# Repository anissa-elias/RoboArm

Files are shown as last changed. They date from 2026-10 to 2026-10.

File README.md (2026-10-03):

# RoboArm

An open, low-cost 6-axis robotic arm built entirely from commercial off-the-shelf (COTS) parts, designed for students to build, program and learn from.

RoboArm aims for the feature set of an educational desktop arm such as the Niryo Ned2 (onboard computer running ROS 2, joint encoders, collision detection, emergency stop) at a fraction of the cost, with every purchased part available on Amazon.

> Status: early design. The electronics schematic and bill of materials are complete and checked. The mechanical design, firmware and ROS 2 software are not started yet.

## Features (planned)

| Feature | How |
|---|---|
| 6 joints + gripper | NEMA 17 stepper motors, MG996R gripper servo |
| Onboard brain | Raspberry Pi 5 running ROS 2 Jazzy (Ubuntu 24.04) |
| Real-time motion | Arduino Mega 2560 generating step pulses |
| Quiet drivers | TMC2209 stepper drivers |
| Knows where it is at power-up | AS5600 absolute magnetic encoder on every joint output, no homing move |
| Collision and load sensing | TMC2209 StallGuard load readings over UART, per joint |
| Safety | Latching E-stop that drops a relay on the 24 V motor bus |
| Simple to source | Every purchased part on Amazon |

## How it works

```
Raspberry Pi 5 (ROS 2)  --USB-->  Arduino Mega 2560  --STEP/DIR/EN-->  6x TMC2209  -->  6x NEMA 17
                                       |  <--UART (load, temperature, open-wire)--  TMC2209
                                       |  <--analog angle--  6x AS5600 joint encoders
                                       +--PWM-->  gripper servo

24 V bench supply -> 10 A fuse -> E-stop relay -> 24 V bus -> drivers
                                                          -> 2 A fuse -> 6 V buck -> gripper servo
Pi 5 has its own USB-C supply and powers the Mega over USB.
```

Details: [docs/architecture.md](docs/architecture.md).

## Repository layout

| Folder | Contents |
|---|---|
| [hardware/electronics/](hardware/electronics/) | KiCad schematic (every pin shown), generator script, connection checker, PDF |
| [hardware/bom/](hardware/bom/) | Bill of materials with Amazon links |
| [hardware/mechanical/](hardware/mechanical/) | 3D-printed body, CAD, print settings (open) |
| [firmware/](firmware/) | Arduino Mega firmware (open) |
| [software/](software/) | ROS 2 packages, simulation, tools (open) |
| [docs/](docs/) | Architecture, design decisions, roadmap |

## Cost

Electronics and motors: about **$268** before tax and shipping (estimate, see [hardware/bom/](hardware/bom/)). This excludes the Raspberry Pi 5, its power supply, the Arduino Mega, a 24 V bench supply, printed parts and mechanical hardware. Target: a complete arm cheaper than comparable open-source arms.

## Roadmap

See [docs/roadmap.md](docs/roadmap.md).

## Related open-source arms

RoboArm learns from existing open designs, including [Thor](https://github.com/AngelLM/Thor), [PAROL6](https://github.com/Source-Robotics/PAROL6-Desktop-robot-arm), [Faze4](https://github.com/Source-Robotics/Faze4-Robotic-arm), [SmallRobotArm](https://github.com/SkyentificGit/SmallRobotArm) and the [AR4](https://www.anninrobotics.com). See [docs/comparison.md](docs/comparison.md).

## Safety

This is an experimental machine. Motors can move suddenly and pinch. Keep the E-stop within reach, set a current limit on the supply during first tests, and never plug or unplug a motor with power applied.

## License

To be decided.

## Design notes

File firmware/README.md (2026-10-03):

# Firmware (Arduino Mega 2560)

`roboarm_mega/` is the motion-controller firmware. Pin map: [docs/architecture.md](../docs/architecture.md#arduino-mega-pin-map).

| File | Contents |
|---|---|
| `roboarm_mega.ino` | Serial protocol to the Pi, safety checks, gripper |
| `motion.cpp/.h` | Step generation (Timer2 ISR, 20 kHz) and per-joint trapezoidal velocity planning, all joints arrive together |
| `sensors.cpp/.h` | AS5600 encoder reading and zero offsets (EEPROM), TMC2209 UART setup and polling (load, over-temperature, open wire) |
| `config.h` | Pins, gear ratios, limits, currents, speeds. **Gear ratios and limits are placeholders until the mechanical design exists.** |

## Build

```bash
arduino-cli core install arduino:avr
arduino-cli lib install TMCStepper Servo
arduino-cli compile -b arduino:avr:mega firmware/roboarm_mega
# with nothing connected (fake encoders and drivers):
arduino-cli compile -b arduino:avr:mega --build-property build.extra_flags=-DRA_SIM=1 firmware/roboarm_mega
```

Or use the dev image, which has the toolchain: see [software/README.md](../software/README.md).

## Protocol (USB serial, 115200 baud, one command per line)

| Command | Meaning |
|---|---|
| `P` | Ping (keeps the 1 s link watchdog alive) |
| `E 1` / `E 0` | Enable / disable all drivers |
| `M a1 ... a6` | Move all joints to angles (degrees) |
| `J n a` | Move joint n to angle a |
| `X` | Stop smoothly |
| `V dps` / `A dps2` | Max joint speed / acceleration |
| `G a`, `G O`, `G C` | Gripper angle, open, close |
| `S` | Status line |
| `T hz` | Stream status (0 = off, max 50) |
| `Z` | Current pose becomes encoder zero (saved) |
| `R` | Re-sync step counters to encoders |
| `L n thr` | StallGuard threshold for joint n (0 = off) |
| `C` | Clear faults |

Status line: `S <faults> <enabled> <moving> | 6 commanded angles | 6 encoder angles | 6 loads | 6 driver flags`.
Fault bits: 1 link lost, 2 collision, 4 following error (> 5 deg between commanded and encoder), 8 no motor power (E-stop or 24 V off), 16 driver fault (open wire).

## Known limits (from the design review)

- The ATmega2560 tops out around 10 kHz steps per joint; with large gear reductions this limits joint speed. A faster motion MCU (Teensy 4.1 or a 6-driver STM32 board) is under consideration.
- TMC2209 registers reset when motor power drops; the firmware re-sends settings when a driver answers again, and stays disabled until faults are cleared.
- StallGuard only works while moving, in StealthChop; collision detection relies mainly on the encoder following error.
- TODO: E-stop input to the MCU, DIAG pin interrupts, encoder range/linearity calibration.

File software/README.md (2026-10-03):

# Software (Raspberry Pi 5)

Target: Ubuntu 24.04 with ROS 2 Jazzy on the Raspberry Pi 5, run in Docker so the same environment works on a dev machine and on the Pi.

## Dev environment (Docker)

`docker/Dockerfile` builds `roboarm-dev:jazzy`: ROS 2 Jazzy, ros2_control, Arduino CLI with the AVR core and firmware libraries, and Python serial tools. The same Dockerfile builds for amd64 (dev machine or VM) and arm64 (Raspberry Pi 5).

```bash
docker compose -f software/docker/compose.yaml build
docker compose -f software/docker/compose.yaml run --rm dev        # shell with the repo at /roboarm
```

On the Pi with the Mega plugged in, uncomment the `devices:` block in `compose.yaml` to pass `/dev/ttyACM0` into the container.

## Working with nothing connected

| Tool | Purpose |
|---|---|
| `tools/mock_mega.py` | Fake Mega on a virtual serial port; speaks the firmware protocol and moves joints at the set speed |
| `tools/roboarm_cli.py` | Terminal for the Mega (real or mock); `--demo` runs a scripted test |
| `tools/smoke_test.sh` | Builds the firmware and runs the CLI demo against the mock |

```bash
docker compose -f software/docker/compose.yaml run --rm dev bash software/tools/smoke_test.sh
```

## Planned packages

| Package | Purpose |
|---|---|
| `roboarm_description` | URDF model of the arm |
| `roboarm_hardware` | ros2_control hardware interface talking to the Mega over USB serial |
| `roboarm_moveit_config` | MoveIt 2 motion planning |
| `roboarm_bringup` | Launch files |
| `roboarm_sim` | Simulation (MuJoCo or Gazebo) |

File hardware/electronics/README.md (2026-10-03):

# Electronics

Single-sheet KiCad 9 schematic of the full RoboArm wiring. Every board pin is shown; parts are joined by drawn wires (red = 24 V bus, black = motor ground return, orange = 6 V servo rail).

| File | Purpose |
|---|---|
| `custom_arm.kicad_sch` | Schematic (open in KiCad 9) |
| `output/roboarm_schematic.pdf` | PDF export (A1) |
| `generate_schematic.py` | Generates the schematic from code |
| `verify_netlist.py` | Checks every intended connection in the exported netlist |
| `ArmModules.kicad_sym`, `sym-lib-table` | Custom symbols (Pi 5, Mega, TMC2209 module, AS5600 module, supplies, relay) |

## Regenerate and check

```bash
python generate_schematic.py
kicad-cli sch erc custom_arm.kicad_sch
kicad-cli sch export netlist -o output/arm.net custom_arm.kicad_sch
python verify_netlist.py output/arm.net
kicad-cli sch export pdf -o output/roboarm_schematic.pdf custom_arm.kicad_sch
```

Edit the generator, not the `.kicad_sch` file, so the two stay in sync.

## Before building

- TMC2209 module pin names differ between vendors; check the silkscreen.
- TMC2209 VM maximum is about 29 V: 24 V only.
- Set each driver's current and the buck module's 6.0 V output with a meter before connecting motors or the servo.
- Confirm the AS5600 modules run at 5 V.

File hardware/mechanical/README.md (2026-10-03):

# Mechanical

Not started. This folder will hold the 3D-printed body, CAD sources and print settings.

## To decide

- Body: adapt an existing open design or design a RoboArm body from scratch. If an existing design is adapted, follow its license and credit it.
- Joint layout and gear ratios for each of the 6 joints.
- Motor sizes per joint (the current BOM assumes 59 Ncm motors on joints 1-3 and short 16 Ncm motors on joints 4-6).
- Mounts for the AS5600 encoder magnets on each joint OUTPUT shaft, so the measured angle is the true joint angle.
- Cable routing through the joints.
- Mount for the driver carrier board, Mega, Pi 5 and E-stop in the base.

## Planned layout

| Folder | Contents |
|---|---|
| `cad/` | Source CAD files |
| `stl/` | Printable parts |
| `print-settings.md` | Material, layer height, infill per part |
| `assembly.md` | Assembly guide |

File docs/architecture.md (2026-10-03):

# Architecture

## Block diagram

```
                         +------------------+
                         |  Raspberry Pi 5  |  ROS 2 Jazzy: kinematics, planning, UI
                         +--------+---------+
                                  | USB (commands, telemetry; also powers the Mega)
                         +--------v---------+
                         | Arduino Mega 2560|  real-time step generation, sensor reading
                         +--+----+----+--+--+
        STEP/DIR/EN (x6)    |    |    |  |  PWM D9
              +-------------+    |    |  +-------------> gripper servo (6 V)
              v                  |    |
        +-----------+  UART x2   |    |  analog A0-A5
        | 6x TMC2209|<-----------+    +<------------ 6x AS5600 joint encoders
        +-----+-----+
              | 4 wires each
              v
        6x NEMA 17 stepper motors
```

## Power

| Rail | Source | Feeds | Notes |
|---|---|---|---|
| 24 V motor bus | Bench supply (first tests, 3 A limit), later Mean Well LRS-200-24 | TMC2209 VM pins, gripper buck | 10 A fuse F0, then E-stop relay K1 |
| 6 V servo | XL4015 buck from the 24 V bus | MG996R gripper servo | 2 A fuse in, 3 A fuse out; set 6.0 V before connecting |
| 5 V logic | Mega 5 V pin (from Pi USB) | TMC2209 VDD, encoders, pull-ups | Logic only, never motor current |
| Pi 5 V | Official Pi 27 W USB-C supply | Raspberry Pi 5 | Separate from the motor supply |

All grounds are common. The 24 V bus never touches the Pi or the Mega.

## Arduino Mega pin map

| Function | Pins |
|---|---|
| STEP joint 1-6 | D22-D27 |
| DIR joint 1-6 | D30-D35 |
| EN joint 1-6 (LOW = driver on) | D36-D41, 10k pull-up holds drivers off during boot |
| Encoder angle joint 1-6 | A0-A5 (1k + 100 nF filter at the Mega) |
| TMC2209 UART bus A (joints 1-3) | Serial2: TX2 D16 (through 1k), RX2 D17 |
| TMC2209 UART bus B (joints 4-6) | Serial3: TX3 D14 (through 1k), RX3 D15 |
| Gripper servo PWM | D9 (through 1k) |
| Spare | D0-D8, D10-D13, D18-D21, D28-D29, D42-D53, A6-A15 |

## Design decisions

- **Absolute encoders instead of homing switches.** Each AS5600 reads a magnet on the joint output shaft (after any gearbox), so the arm knows every joint angle at power-up. This matches commercial arms and also catches skipped steps.
- **TMC2209 in UART mode.** MS1/MS2 set each driver's bus address (0-2); microstepping and current are set over UART. StallGuard gives a per-joint load reading for collision detection, plus over-temperature and open-wire flags.
- **E-stop drops a relay, not the motor current directly.** The button breaks the relay coil circuit, so pressing it or breaking its wire cuts the 24 V bus (fail-safe). The Pi and Mega stay powered.
- **No brakes.** Like the Niryo Ned2. The arm can sag when motor power is cut; support it during testing.
- **Centralized drivers.** Driver modules sit on one perfboard near the Mega. Per-joint smart modules on a CAN bus (as on commercial arms) are a possible later revision.

## Schematic

[hardware/electronics/output/roboarm_schematic.pdf](../hardware/electronics/output/roboarm_schematic.pdf), generated from [hardware/electronics/generate_schematic.py](../hardware/electronics/generate_schematic.py).

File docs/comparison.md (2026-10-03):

# Comparison with other arms

Checked October 2026. Specifications are from each project's own documentation.

| | RoboArm (planned) | Niryo Ned2 | Thor | PAROL6 | Faze4 |
|---|---|---|---|---|---|
| Joints | 6 + gripper | 6 + gripper | 6 + gripper | 6 + gripper | 6 + gripper |
| Onboard computer | Raspberry Pi 5, ROS 2 Jazzy | Raspberry Pi 4, ROS | None (PC) | None (PC) | None (PC) |
| Motion controller | Arduino Mega 2560 | Built in | Arduino Mega + Thor control PCB | STM32 board, TMC5160 | Teensy 3.5 |
| Joint position feedback | AS5600 absolute encoders | Magnetic encoders | None | Not listed | Limit switches |
| Collision detection | TMC2209 StallGuard | Yes | No | Not listed | No |
| E-stop | Yes (relay) | Not listed in specs | No | Not listed | No |
| Payload | TBD (body not designed) | 300 g | 750 g | 1 kg near base | Not listed |
| License | TBD | Commercial | CC-BY-SA 4.0 | GPL-3.0 | CERN-OHL-S 2.0 |
| Cost | Target below comparable open arms | Several thousand USD | Under 350 EUR | About 1,190 EUR partial kit | Under 1,000 USD |

Sources:
[Niryo Ned2 specifications](https://docs.niryo.com/robots/ned2/technical-specifications/) ·
[Thor](https://github.com/AngelLM/Thor) ·
[PAROL6 specifications](https://source-robotics.github.io/PAROL-docs/page2_2/) ·
[Faze4](https://github.com/Source-Robotics/Faze4-Robotic-arm)

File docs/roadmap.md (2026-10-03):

# Roadmap

## Done

- [x] Electronics architecture (Pi 5, Mega, TMC2209, AS5600, E-stop)
- [x] Full-pin KiCad schematic with automated connection check
- [x] Amazon bill of materials

## Next

### Mechanical
- [ ] Choose the body: adapt an existing open design or design a RoboArm body
- [ ] Joint layout, gear ratios and motor sizes per joint
- [ ] Encoder magnet mounts on each joint output
- [ ] Printed parts list, materials and print settings
- [ ] Assembly guide

### Electronics
- [ ] Order parts and bench-test one joint (driver, motor, encoder)
- [ ] Driver carrier perfboard layout
- [ ] Wiring harness and connectors per joint
- [ ] Optional: custom PCB replacing the perfboard

### Firmware (Arduino Mega)
- [ ] Six-axis step generation with acceleration
- [ ] Encoder reading and joint-angle calibration
- [ ] TMC2209 UART setup (current, microstepping, StallGuard)
- [ ] Collision detection and fault handling
- [ ] Serial protocol to the Pi

### Software (Raspberry Pi 5)
- [ ] URDF robot model
- [ ] ros2_control hardware interface
- [ ] MoveIt 2 configuration
- [ ] Simulation (MuJoCo or Gazebo)
- [ ] Simple operator UI

### Docs
- [ ] Build guide for students
- [ ] Safety checklist

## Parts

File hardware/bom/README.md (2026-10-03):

# Bill of materials

All purchased parts from Amazon. Prices are estimates (October 2026) before tax and shipping; check the cart. Machine-readable version: [bom.csv](bom.csv).

## Electronics and motors

| Ref | Part | Buy | Est. |
|---|---|---|---|
| DRV1-DRV6 | BIGTREETECH TMC2209 V1.3 drivers with heatsinks | [5-pack + 1 single](https://www.amazon.com/BIGTREETECH-DIRECT-TMC2209-Stepsticks-Motherboard/dp/B07ZQ3C1XW) | $40 |
| M1-M3 | STEPPERONLINE NEMA 17 17HS19-2004S1, 59 Ncm, 2 A (with 1 m cables) | [3-pack](https://www.amazon.com/Stepper-Motor-59Ncm-4-wire-Printer/dp/B00Y2HJE22) | $30 |
| M4-M6 | STEPPERONLINE short-body NEMA 17 17HS08-1004S, 16 Ncm, 1 A | [x3](https://www.amazon.com/STEPPERONLINE-Bipolar-Stepper-22-6oz-Extruder/dp/B00PNEQ79Q) | $33 |
| M7 | MG996R servo (gripper) | [4-pack](https://www.amazon.com/MG996R-Copper-Digital-Helicopter-Control/dp/B0DK1V5ZSM) | $17 |
| ENC1-ENC6 | AS5600 magnetic encoder modules with magnets (confirm 5 V support) | [10-pack](https://www.amazon.com/AS5600-Magnetic-Encoder-Induction-Measurement/dp/B0D3WMK5MT) | $15 |
| U6 | XL4015 5 A buck module (set to 6.0 V) | [3-pack](https://www.amazon.com/HiLetgo-1-25-36V-Converter-Adjustable-Step-down/dp/B00LOG4XC0) | $10 |
| SW1 | E-stop, 22 mm latching mushroom, 1 NC, twist release | [COMOK](https://www.amazon.com/COMOK-Emergency-Self-Locking-Push-Button-ZB2-BE102C/dp/B07MJPRMRL) | $9 |
| K1 | 24 V 30 A relay, normally open, with wired socket | [link](https://www.amazon.com/Normally-Automotive-Relay-18AWG-Socket/dp/B0CQFG7WZV) | $8 |
| F0-F2 | Inline ATO fuse holders with fuse assortment | [5-pack kit](https://www.amazon.com/Inline-Holder-Blade-3-2Ft-Electric/dp/B0B4JTWJDT) | $12 |
| C7, C20-C25 | Electrolytic capacitors: 1000 uF 16 V (x1), 100 uF 35 V (x6) | [assortment](https://www.amazon.com/OQATNXUR-Electrolytic-Capacitor-Assortment-1000uf/dp/B0DDCB76H9) | $12 |
| C1-C6, C8 | Ceramic 100 nF | [assortment](https://www.amazon.com/BOJACK-Ceramic-Capacitor-Assortment-Capacitors/dp/B07P8N8BW9) | $10 |
| R1-R6, R13, R21-R26, R31-R32 | 1k (x9), 10k (x6) metal film 1/4 W | [ELEGOO kit](https://www.amazon.com/Elegoo-Values-Resistor-Assortment-Compliant/dp/B072BL2VX1) | $10 |
| - | Driver carrier: prototype board | [ElectroCookie 3-pack](https://www.amazon.com/Prototype-Solderable-Breadboard-Electronics-Gold-Plated/dp/B082KY5Y5Z) | $12 |
| - | 2.54 mm female headers (driver sockets) | [Glarks kit](https://www.amazon.com/Glarks-Straight-Connector-Assortment-Prototype/dp/B076GZXW3Z) | $8 |
| - | 40 mm 5 V fan over the driver row | [WINSINN 2-pack](https://www.amazon.com/WINSINN-Bearings-Brushless-Cooling-40mm10mm/dp/B08R9JJDYP) | $9 |
| - | USB-A to USB-B cable (Pi to Mega) | [Amazon Basics](https://www.amazon.com/amazonbasics-usb-2-0-cable-male/dp/b00nh11kik) | $5 |
| - | 18 AWG silicone wire (24 V, motors) | [CBAZY](https://www.amazon.com/CBAZY-Stranded-Flexible-Silicone-Electric/dp/B073RDBW7L) | $15 |
| - | 22 AWG silicone wire (signals) | [CBAZY](https://www.amazon.com/CBAZY-Flexible-Silicone-Stranded-Electric/dp/B073RF4YY4) | $13 |
| | **Total** | | **about $268** |

## Not included above

- Raspberry Pi 5 (8 GB) and official 27 W USB-C supply
- Arduino Mega 2560
- 24 V power supply (lab bench supply with current limit for first tests; Mean Well LRS-200-24 or similar later)
- Printed parts, bearings, belts, gearboxes and fasteners (depend on the mechanical design)

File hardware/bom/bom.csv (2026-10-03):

Reference | Part | Buy | Amazon link | Est USD
DRV1-6 | BIGTREETECH TMC2209 V1.3 drivers with heatsinks (5-pack) + 1 single | 1 pack + 1 | https://www.amazon.com/BIGTREETECH-DIRECT-TMC2209-Stepsticks-Motherboard/dp/B07ZQ3C1XW | 40
M1-M3 | STEPPERONLINE Nema 17 17HS19-2004S1, 59 Ncm 2 A, 3-pack with 1 m cables | 1 pack | https://www.amazon.com/Stepper-Motor-59Ncm-4-wire-Printer/dp/B00Y2HJE22 | 30
M4-M6 | STEPPERONLINE short-body Nema 17 (17HS08-1004S), 16 Ncm 1 A | 3 | https://www.amazon.com/STEPPERONLINE-Bipolar-Stepper-22-6oz-Extruder/dp/B00PNEQ79Q | 33
U6 | HiLetgo XL4015 5 A buck module, 3-pack | 1 pack | https://www.amazon.com/HiLetgo-1-25-36V-Converter-Adjustable-Step-down/dp/B00LOG4XC0 | 10
M7 | MG996R servo, 4-pack (Deegoo-FPV) | 1 pack | https://www.amazon.com/MG996R-Copper-Digital-Helicopter-Control/dp/B0DK1V5ZSM | 17
ENC1-ENC6 | AS5600 magnetic encoder modules with magnets, 10-pack (check 5 V support) | 1 pack | https://www.amazon.com/AS5600-Magnetic-Encoder-Induction-Measurement/dp/B0D3WMK5MT | 15
carrier | ElectroCookie large prototype board, 3-pack | 1 pack | https://www.amazon.com/Prototype-Solderable-Breadboard-Electronics-Gold-Plated/dp/B082KY5Y5Z | 12
carrier | Glarks 2.54 mm female header kit, 120 pcs | 1 kit | https://www.amazon.com/Glarks-Straight-Connector-Assortment-Prototype/dp/B076GZXW3Z | 8
F0-F2 | 16 AWG inline ATO fuse holders with fuse assortment, 5-pack | 1 kit | https://www.amazon.com/Inline-Holder-Blade-3-2Ft-Electric/dp/B0B4JTWJDT | 12
SW1 | E-stop, 22 mm latching red mushroom, 1 NC, twist release | 1 | https://www.amazon.com/COMOK-Emergency-Self-Locking-Push-Button-ZB2-BE102C/dp/B07MJPRMRL | 9
K1 | 24 V 30 A automotive relay, normally open, with wired socket | 1 | https://www.amazon.com/Normally-Automotive-Relay-18AWG-Socket/dp/B0CQFG7WZV | 8
C7,C20-C25 | Electrolytic capacitor assortment (100 uF 35 V, 1000 uF) | 1 kit | https://www.amazon.com/OQATNXUR-Electrolytic-Capacitor-Assortment-1000uf/dp/B0DDCB76H9 | 12
C1-C6,C8 | BOJACK ceramic capacitor kit (includes 100 nF) | 1 kit | https://www.amazon.com/BOJACK-Ceramic-Capacitor-Assortment-Capacitors/dp/B07P8N8BW9 | 10
R1-R6,R13,R21-R26,R31-R32 | ELEGOO 525 pc metal film resistor kit (1k x9, 10k x6) | 1 kit | https://www.amazon.com/Elegoo-Values-Resistor-Assortment-Compliant/dp/B072BL2VX1 | 10
fan | WINSINN 40 mm 5 V fan (2-pack) | 1 pack | https://www.amazon.com/WINSINN-Bearings-Brushless-Cooling-40mm10mm/dp/B08R9JJDYP | 9
USB | Amazon Basics USB-A to USB-B cable, 6 ft | 1 | https://www.amazon.com/amazonbasics-usb-2-0-cable-male/dp/b00nh11kik | 5
wire | CBAZY 18 AWG silicone wire kit (power) | 1 | https://www.amazon.com/CBAZY-Stranded-Flexible-Silicone-Electric/dp/B073RDBW7L | 15
wire | CBAZY 22 AWG silicone wire kit (signals) | 1 | https://www.amazon.com/CBAZY-Flexible-Silicone-Stranded-Electric/dp/B073RF4YY4 | 13
Not included | Raspberry Pi 5 8GB + 27 W USB-C supply, Arduino Mega 2560, 24 V supply, printed parts and mechanical hardware
 | TOTAL (estimate, before tax/shipping) |  |  | 268.0

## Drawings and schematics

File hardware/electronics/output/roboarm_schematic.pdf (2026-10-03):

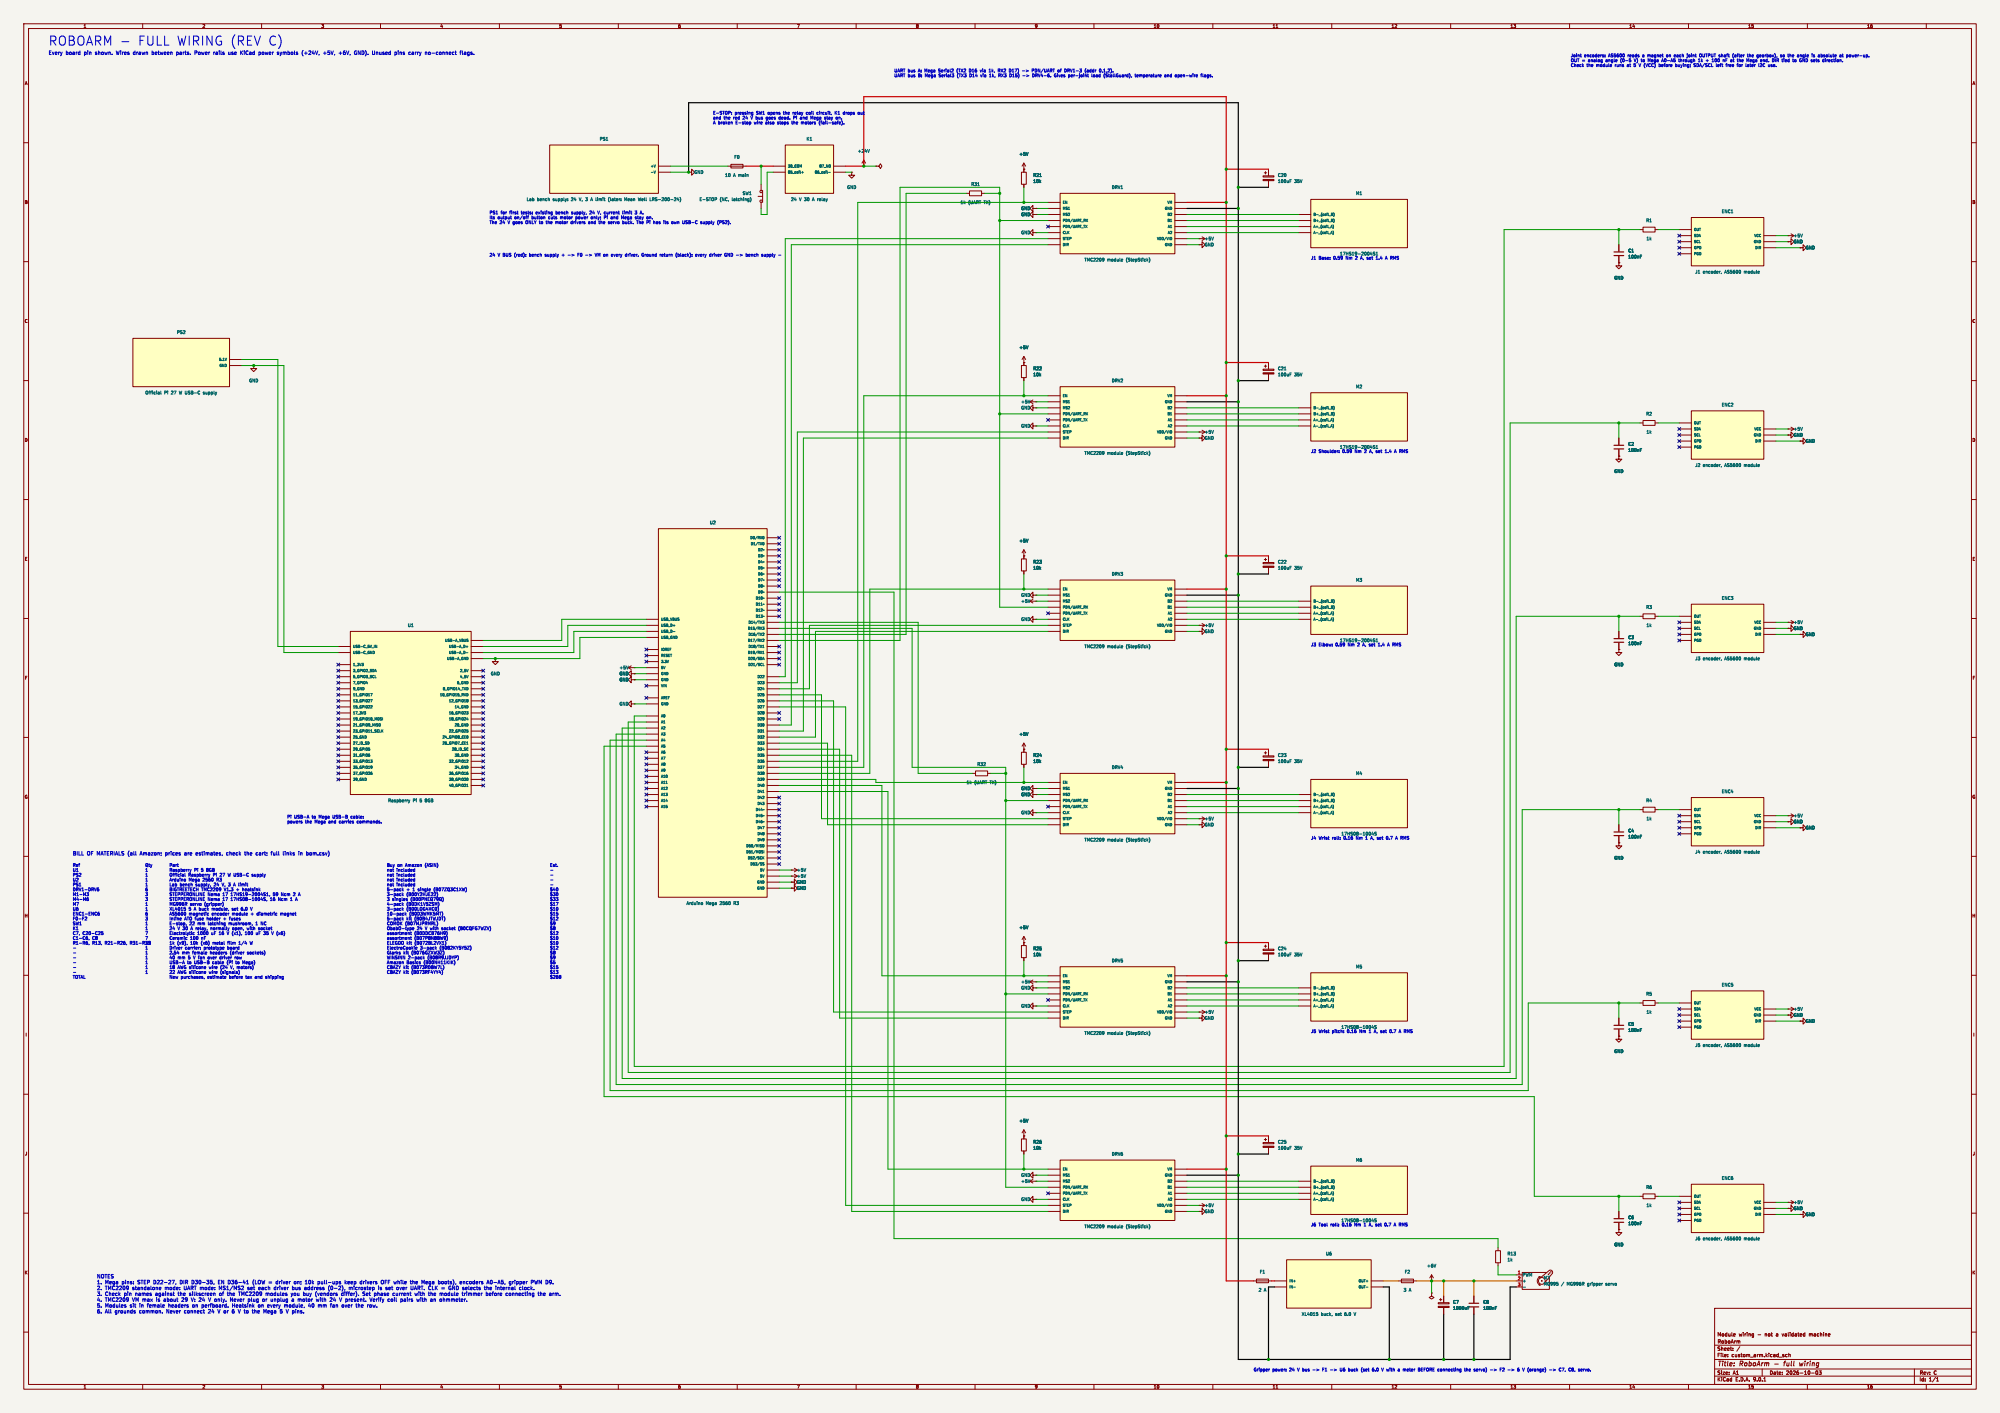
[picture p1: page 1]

J3 Elbow: 0.59 Nm 2 A, set 1.4 A RMS ROBOARM - FULL WIRING (REV C)

SW1 E-STOP (NC, latching) GND

J1 Base: 0.59 Nm 2 A, set 1.4 A RMS

DIR ENC2
J2 encoder, AS5600 module OUT SDA

GND GND

USB-A_VBUS USB-A_D+ USB-A_D- USB-A_GND

Pi USB-A to Mega USB-B cable: powers the Mega and carries commands.

J4 Wrist roll: 0.16 Nm 1 A, set 0.7 A RMS

Buy on Amazon (ASIN) not included

1k (x9), 10k (x6) metal film 1/4 W
2.54 mm female headers (driver sockets) 40 mm 5 V fan over driver row

J5 Wrist pitch: 0.16 Nm 1 A, set 0.7 A RMS

J6 Tool roll: 0.16 Nm 1 A, set 0.7 A RMS

Id: 1/1 Title: RoboArm - full wiring

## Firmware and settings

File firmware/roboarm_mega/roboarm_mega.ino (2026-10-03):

// RoboArm firmware for the Arduino Mega 2560.
//
// The Raspberry Pi sends plain-text commands over USB serial (115200 baud), one per line.
// Angles are joint degrees. Replies start with "OK", "ERR" or a status letter.
//
//   P                     ping (also keeps the link watchdog alive)
//   E 1 | E 0             enable / disable all motor drivers
//   M a1 a2 a3 a4 a5 a6   move all joints to these angles
//   J n a                 move joint n (1-6) to angle a
//   X                     stop smoothly
//   V dps | A dps2        set max joint speed / acceleration
//   G a                   gripper servo angle (or G O / G C for open / close)
//   S                     one status line
//   T hz                  stream status at hz (0 = off, max 50)
//   Z                     current pose becomes encoder zero (saved)
//   R                     re-sync step counters to the encoders
//   L n thr               StallGuard collision threshold for joint n (0 = off)
//   C                     clear faults
//   H                     help
//
// Status line:  S <fault> <en> <moving> | cmd: 6 angles | enc: 6 angles | load: 6 values | drv: 6 flags
// Build with RA_SIM=1 to run with nothing connected.

#include "config.h"
#include "motion.h"
#include "sensors.h"
#include <Servo.h>

enum Fault : uint8_t { F_NONE = 0, F_LINK = 1, F_COLLISION = 2, F_FOLLOW = 4, F_NO_MOTOR_POWER = 8, F_DRIVER = 16 };

static Servo gripper;
static bool enabled = false;
static uint8_t faults = F_NONE;
static uint32_t last_rx_ms = 0, last_stream_ms = 0;
static uint16_t stream_period_ms = 0;
static char line[96];
static uint8_t line_len = 0;

static void setEnabled(bool on) {
  if (on && faults) { Serial.println(F("ERR faults active, send C to clear")); return; }
  enabled = on;
  if (!on) motion::haltNow();
  for (uint8_t j = 0; j < NUM_JOINTS; j++) digitalWrite(PIN_EN[j], on ? LOW : HIGH);
}

static void raise(uint8_t f) {
  if (!(faults & f)) { faults |= f; Serial.print(F("FAULT ")); Serial.println(f); }
  motion::haltNow();
  setEnabled(false);
}

static void printStatus() {
  Serial.print(F("S ")); Serial.print(faults); Serial.print(' ');
  Serial.print(enabled ? 1 : 0); Serial.print(' ');
  Serial.print(motion::moving() ? 1 : 0); Serial.print(F(" |"));
  for (uint8_t j = 0; j < NUM_JOINTS; j++) { Serial.print(' '); Serial.print(motion::positionDeg(j), 2); }
  Serial.print(F(" |"));
  for (uint8_t j = 0; j < NUM_JOINTS; j++) { Serial.print(' '); Serial.print(sensors::encoderDeg(j), 2); }
  Serial.print(F(" |"));
  for (uint8_t j = 0; j < NUM_JOINTS; j++) { Serial.print(' '); Serial.print(sensors::load(j)); }
  Serial.print(F(" |"));
  for (uint8_t j = 0; j < NUM_JOINTS; j++) {
    uint8_t d = (sensors::driverOk(j) ? 1 : 0) | (sensors::overTemp(j) ? 2 : 0) | (sensors::openLoad(j) ? 4 : 0);
    Serial.print(' '); Serial.print(d);
  }
  Serial.println();
}

static void help() {
  Serial.println(F("RoboArm commands: P E M J X V A G S T Z R L C H (see roboarm_mega.ino header)"));
}

static void handle(char *s) {
  char cmd = toupper(s[0]);
  char *args = s + 1;
  switch (cmd) {
    case 'P': Serial.println(F("OK pong")); break;
    case 'E': setEnabled(atoi(args) != 0); if (!faults || !atoi(args)) Serial.println(F("OK")); break;
    case 'M': {
      float a[NUM_JOINTS]; char *p = args;
      for (uint8_t j = 0; j < NUM_JOINTS; j++) {
        char *end; a[j] = strtod(p, &end);
        if (end == p) { Serial.println(F("ERR need 6 angles")); return; }
        p = end;
      }
      if (!enabled) { Serial.println(F("ERR disabled, send E 1")); return; }
      motion::setTargets(a); Serial.println(F("OK"));
      break;
    }
    case 'J': {
      char *end; long n = strtol(args, &end, 10); float a = strtod(end, NULL);
      if (n < 1 || n > NUM_JOINTS) { Serial.println(F("ERR joint 1-6")); return; }
      if (!enabled) { Serial.println(F("ERR disabled, send E 1")); return; }
      motion::setTarget(n - 1, a); Serial.println(F("OK"));
      break;
    }
    case 'X': motion::stopAll(); Serial.println(F("OK")); break;
    case 'V': motion::setVmax(atof(args)); Serial.println(F("OK")); break;
    case 'A': motion::setAcc(atof(args)); Serial.println(F("OK")); break;
    case 'G': {
      while (*args == ' ') args++;
      int a = toupper(*args) == 'O' ? GRIPPER_OPEN_DEG : toupper(*args) == 'C' ? GRIPPER_CLOSED_DEG : atoi(args);
      gripper.write(constrain(a, 0, 180)); Serial.println(F("OK"));
      break;
    }
    case 'S': printStatus(); break;
    case 'T': { int hz = constrain(atoi(args), 0, 50); stream_period_ms = hz ? 1000 / hz : 0; Serial.println(F("OK")); break; }
    case 'Z':
      if (motion::moving()) { Serial.println(F("ERR moving")); return; }
      sensors::zeroEncoders();
      for (uint8_t j = 0; j < NUM_JOINTS; j++) motion::setPositionDeg(j, 0);
      Serial.println(F("OK zeroed"));
      break;
    case 'R':
      if (motion::moving()) { Serial.println(F("ERR moving")); return; }
      for (uint8_t j = 0; j < NUM_JOINTS; j++) motion::setPositionDeg(j, sensors::encoderDeg(j));
      Serial.println(F("OK"));
      break;
    case 'L': {
      char *end; long n = strtol(args, &end, 10); long thr = strtol(end, NULL, 10);
      if (n < 1 || n > NUM_JOINTS) { Serial.println(F("ERR joint 1-6")); return; }
      sensors::setSgThreshold(n - 1, (uint8_t)constrain(thr, 0, 255)); Serial.println(F("OK"));
      break;
    }
    case 'C': faults = F_NONE; Serial.println(F("OK cleared")); break;
    case 'H': help(); break;
    default: Serial.println(F("ERR unknown, H for help"));
  }
}

static void readHost() {
  while (Serial.available()) {
    char c = Serial.read();
    last_rx_ms = millis();
    if (c == '\r') continue;
    if (c == '\n') {
      line[line_len] = 0;
      if (line_len) handle(line);
      line_len = 0;
    } else if (line_len < sizeof(line) - 1) {
      line[line_len++] = c;
    }
  }
}

static void checkSafety() {
  if (!enabled) return;
  if (millis() - last_rx_ms > LINK_TIMEOUT_MS) raise(F_LINK);
  for (uint8_t j = 0; j < NUM_JOINTS; j++) {
    if (!sensors::driverOk(j)) { raise(F_NO_MOTOR_POWER); return; }   // E-stop pressed or 24 V off
    if (sensors::openLoad(j) && motion::moving()) { raise(F_DRIVER); return; }
    float err = fabs(motion::positionDeg(j) - sensors::encoderDeg(j));
    if (err > FOLLOW_ERROR_DEG) { raise(F_FOLLOW); return; }          // skipped steps or blocked joint
    uint8_t thr = sensors::sgThreshold(j);
    uint16_t ld = sensors::load(j);
    if (thr && motion::moving() && ld != 0xFFFF && ld < 2u * thr) { raise(F_COLLISION); return; }
  }
}

void setup() {
  for (uint8_t j = 0; j < NUM_JOINTS; j++) { pinMode(PIN_EN[j], OUTPUT); digitalWrite(PIN_EN[j], HIGH); }
  Serial.begin(HOST_BAUD);
  motion::begin();
  sensors::begin();
  // Encoders are absolute: start the step counters at the measured joint angles.
  for (uint8_t j = 0; j < NUM_JOINTS; j++) motion::setPositionDeg(j, sensors::encoderDeg(j));
  gripper.attach(PIN_GRIPPER);
  gripper.write(GRIPPER_OPEN_DEG);
  last_rx_ms = millis();
  Serial.print(F("RoboArm firmware ready"));
  Serial.println(RA_SIM ? F(" (SIM mode)") : F(""));
}

void loop() {
  readHost();
  motion::update();
  sensors::update();
  checkSafety();
  if (stream_period_ms && millis() - last_stream_ms >= stream_period_ms) {
    last_stream_ms = millis();
    printStatus();
  }
}

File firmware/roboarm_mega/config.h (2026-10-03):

// RoboArm firmware configuration (Arduino Mega 2560).
// Pin map matches hardware/electronics (see docs/architecture.md).
#pragma once
#include <Arduino.h>

// ---------------------------------------------------------------- build options
// RA_SIM 1: run with nothing connected. Encoders report the commanded position,
// TMC2209 UART is skipped, the driver-power check always passes.
#ifndef RA_SIM
#define RA_SIM 0
#endif

#define NUM_JOINTS 6
#define HOST_BAUD 115200      // USB serial to the Raspberry Pi
#define TMC_BAUD 115200       // TMC2209 single-wire UART

// ---------------------------------------------------------------- pins
// STEP D22-D27 = PORTA bits 0-5 (written directly in the step ISR)
// DIR  D30-D35, EN D36-D41 (LOW = driver enabled, 10k pull-ups hold them off at boot)
static const uint8_t PIN_DIR[NUM_JOINTS] = {30, 31, 32, 33, 34, 35};
static const uint8_t PIN_EN[NUM_JOINTS]  = {36, 37, 38, 39, 40, 41};
static const uint8_t PIN_ENC[NUM_JOINTS] = {A0, A1, A2, A3, A4, A5};
static const uint8_t PIN_GRIPPER = 9;

// TMC2209 UART buses: joints 1-3 on Serial2, joints 4-6 on Serial3, addresses 0,1,2
static const uint8_t TMC_ADDR[NUM_JOINTS] = {0, 1, 2, 0, 1, 2};

// ---------------------------------------------------------------- joints
// GEAR_RATIO and limits are PLACEHOLDERS until the mechanical design is chosen.
static const uint16_t MOTOR_STEPS = 200;   // 1.8 deg steppers
static const uint16_t MICROSTEPS = 8;
static const float GEAR_RATIO[NUM_JOINTS]   = {10.0, 10.0, 10.0, 5.0, 5.0, 5.0};
static const int8_t   DIR_SIGN[NUM_JOINTS]  = {1, 1, 1, 1, 1, 1};
static const int8_t   ENC_SIGN[NUM_JOINTS]  = {1, 1, 1, 1, 1, 1};
static const float LIMIT_MIN[NUM_JOINTS]    = {-170, -90, -135, -170, -110, -180};
static const float LIMIT_MAX[NUM_JOINTS]    = { 170,  90,  135,  170,  110,  180};
// Motor RMS current (mA): 17HS19-2004S1 on J1-J3, 17HS08-1004S on J4-J6
static const uint16_t RMS_MA[NUM_JOINTS]    = {1400, 1400, 1400, 700, 700, 700};
static const float R_SENSE = 0.11f;        // BIGTREETECH TMC2209 V1.3 sense resistor

// ---------------------------------------------------------------- motion
static const uint32_t STEP_ISR_HZ = 20000;   // step timer rate; max 10 kHz steps per joint
static const float DEFAULT_VMAX_DPS = 30.0f; // joint speed, degrees per second
static const float DEFAULT_ACC_DPS2 = 60.0f; // joint acceleration, degrees per second^2
static const uint16_t CONTROL_HZ = 500;      // velocity planner rate

// ---------------------------------------------------------------- safety
static const uint16_t LINK_TIMEOUT_MS = 1000;   // no host message while enabled -> stop + disable
static const uint8_t  SG_THRESHOLD_DEFAULT = 0; // StallGuard collision threshold, 0 = off (tune per joint)
static const float    FOLLOW_ERROR_DEG = 5.0f;  // commanded vs encoder mismatch that raises a fault

// ---------------------------------------------------------------- gripper
static const uint8_t GRIPPER_OPEN_DEG = 20;
static const uint8_t GRIPPER_CLOSED_DEG = 110;

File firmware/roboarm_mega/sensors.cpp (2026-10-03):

#include "sensors.h"
#include "motion.h"
#include <EEPROM.h>
#include <TMCStepper.h>

namespace sensors {

static TMC2209Stepper drv[NUM_JOINTS] = {
  TMC2209Stepper(&Serial2, R_SENSE, TMC_ADDR[0]),
  TMC2209Stepper(&Serial2, R_SENSE, TMC_ADDR[1]),
  TMC2209Stepper(&Serial2, R_SENSE, TMC_ADDR[2]),
  TMC2209Stepper(&Serial3, R_SENSE, TMC_ADDR[3]),
  TMC2209Stepper(&Serial3, R_SENSE, TMC_ADDR[4]),
  TMC2209Stepper(&Serial3, R_SENSE, TMC_ADDR[5]),
};

static float enc_offset[NUM_JOINTS];
static float enc_deg[NUM_JOINTS];
static bool ok[NUM_JOINTS];
static uint16_t sg[NUM_JOINTS];
static bool ot[NUM_JOINTS], ol[NUM_JOINTS];
static uint8_t sg_thr[NUM_JOINTS];
static uint8_t poll_idx = 0;
static uint32_t last_enc_ms = 0, last_poll_ms = 0;

static const int EE_MAGIC = 0, EE_OFFSETS = 4;
static const uint32_t MAGIC = 0x52414131UL;  // "RAA1"

static float wrap180(float a) {
  while (a > 180.0f) a -= 360.0f;
  while (a < -180.0f) a += 360.0f;
  return a;
}

static float rawDeg(uint8_t j) {
  // AS5600 analog output: 0..VCC maps to 0..360 degrees; Mega ADC is 10-bit.
  return analogRead(PIN_ENC[j]) * (360.0f / 1024.0f);
}

void configureDrivers() {
#if !RA_SIM
  for (uint8_t j = 0; j < NUM_JOINTS; j++) {
    TMC2209Stepper &d = drv[j];
    d.begin();
    d.pdn_disable(true);        // PDN_UART pin is the UART, not power-down
    d.mstep_reg_select(true);   // microsteps from register, MS1/MS2 are the address
    d.I_scale_analog(false);
    d.toff(4);
    d.blank_time(24);
    d.rms_current(RMS_MA[j]);
    d.microsteps(MICROSTEPS);
    d.en_spreadCycle(false);    // StealthChop: quiet, and required for StallGuard4
    d.pwm_autoscale(true);
    d.TCOOLTHRS(0xFFFFF);       // StallGuard active at all speeds above standstill
    d.SGTHRS(sg_thr[j]);
    ok[j] = d.test_connection() == 0;
  }
#else
  for (uint8_t j = 0; j < NUM_JOINTS; j++) ok[j] = true;
#endif
}

void begin() {
  Serial2.begin(TMC_BAUD);
  Serial3.begin(TMC_BAUD);
  uint32_t m;
  EEPROM.get(EE_MAGIC, m);
  for (uint8_t j = 0; j < NUM_JOINTS; j++) {
    if (m == MAGIC) EEPROM.get(EE_OFFSETS + j * sizeof(float), enc_offset[j]);
    else enc_offset[j] = 0;
    sg[j] = 0xFFFF; sg_thr[j] = SG_THRESHOLD_DEFAULT; ot[j] = ol[j] = false;
  }
  configureDrivers();
  for (uint8_t j = 0; j < NUM_JOINTS; j++) {
#if RA_SIM
    enc_deg[j] = 0;
#else
    enc_deg[j] = wrap180(ENC_SIGN[j] * rawDeg(j) - enc_offset[j]);
#endif
  }
}

void update() {
  uint32_t now = millis();
  if (now - last_enc_ms >= 10) {        // 100 Hz encoder sampling
    last_enc_ms = now;
    for (uint8_t j = 0; j < NUM_JOINTS; j++) {
#if RA_SIM
      enc_deg[j] = motion::positionDeg(j);
#else
      float a = wrap180(ENC_SIGN[j] * rawDeg(j) - enc_offset[j]);
      enc_deg[j] = 0.7f * enc_deg[j] + 0.3f * a;   // light smoothing
#endif
    }
  }
#if !RA_SIM
  if (now - last_poll_ms >= 20) {       // one driver per 20 ms: each joint every 120 ms
    last_poll_ms = now;
    TMC2209Stepper &d = drv[poll_idx];
    bool was_ok = ok[poll_idx];
    ok[poll_idx] = d.test_connection() == 0;
    if (ok[poll_idx]) {
      if (!was_ok) configureDrivers();  // motor power came back: re-send settings
      sg[poll_idx] = d.SG_RESULT();
      uint32_t st = d.DRV_STATUS();
      ot[poll_idx] = st & (1UL << 1);           // otpw: over-temperature pre-warning
      ol[poll_idx] = st & ((1UL << 6) | (1UL << 7));  // ola/olb: open load
    } else {
      sg[poll_idx] = 0xFFFF;
    }
    poll_idx = (poll_idx + 1) % NUM_JOINTS;
  }
#endif
}

float encoderDeg(uint8_t j) { return enc_deg[j]; }

void zeroEncoders() {
  for (uint8_t j = 0; j < NUM_JOINTS; j++) {
#if RA_SIM
    enc_offset[j] = 0;
#else
    enc_offset[j] = ENC_SIGN[j] * rawDeg(j);
#endif
    EEPROM.put(EE_OFFSETS + j * sizeof(float), enc_offset[j]);
    enc_deg[j] = 0;
  }
  EEPROM.put(EE_MAGIC, MAGIC);
}

bool driverOk(uint8_t j) { return ok[j]; }
uint16_t load(uint8_t j) { return sg[j]; }
bool overTemp(uint8_t j) { return ot[j]; }
bool openLoad(uint8_t j) { return ol[j]; }
void setSgThreshold(uint8_t j, uint8_t thr) {
  sg_thr[j] = thr;
#if !RA_SIM
  drv[j].SGTHRS(thr);
#endif
}
uint8_t sgThreshold(uint8_t j) { return sg_thr[j]; }

}  // namespace sensors

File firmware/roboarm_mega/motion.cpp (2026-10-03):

#include "motion.h"
#include <util/atomic.h>

namespace motion {

// Shared with the ISR. vel_q16: steps per ISR tick in 16.16 fixed point, signed.
static volatile int32_t pos_steps[NUM_JOINTS];
static volatile int32_t vel_q16[NUM_JOINTS];
static uint32_t acc_q16[NUM_JOINTS];      // ISR-only phase accumulators

static int32_t target_steps[NUM_JOINTS];
static float vel_sps[NUM_JOINTS];         // planner velocity, steps per second (signed)
static float vmax_dps = DEFAULT_VMAX_DPS;
static float acc_dps2 = DEFAULT_ACC_DPS2;
static float spd[NUM_JOINTS];             // steps per degree
static float axis_vmax[NUM_JOINTS];       // per-axis speed so all joints arrive together
static float axis_acc[NUM_JOINTS];
static uint32_t last_us = 0;
static bool halted = false;

float stepsPerDeg(uint8_t j) { return spd[j]; }

static void syncAxes() {
  // Scale each joint's speed by its share of the longest move so they finish together.
  float dist[NUM_JOINTS], longest = 0;
  for (uint8_t j = 0; j < NUM_JOINTS; j++) {
    int32_t p;
    ATOMIC_BLOCK(ATOMIC_RESTORESTATE) { p = pos_steps[j]; }
    dist[j] = fabs((float)(target_steps[j] - p)) / spd[j];
    if (dist[j] > longest) longest = dist[j];
  }
  for (uint8_t j = 0; j < NUM_JOINTS; j++) {
    float share = longest > 0 ? dist[j] / longest : 1.0f;
    if (share < 0.05f) share = 0.05f;
    axis_vmax[j] = vmax_dps * share * spd[j];
    axis_acc[j] = acc_dps2 * share * spd[j];
  }
}

void begin() {
  for (uint8_t j = 0; j < NUM_JOINTS; j++) {
    spd[j] = (float)MOTOR_STEPS * MICROSTEPS * GEAR_RATIO[j] / 360.0f;
    pos_steps[j] = 0; vel_q16[j] = 0; acc_q16[j] = 0; target_steps[j] = 0; vel_sps[j] = 0;
    pinMode(PIN_DIR[j], OUTPUT);
  }
  DDRA |= 0x3F;   // STEP pins D22-D27
  PORTA &= ~0x3F;
  syncAxes();
  // Timer2 (Timers 1/3/4/5 belong to the Servo library on the Mega), CTC mode, prescaler 8:
  // 16 MHz / 8 / (OCR2A + 1) = STEP_ISR_HZ
  cli();
  TCCR2A = (1 << WGM21); TCCR2B = (1 << CS21); TCNT2 = 0;
  OCR2A = (F_CPU / 8 / STEP_ISR_HZ) - 1;
  TIMSK2 |= (1 << OCIE2A);
  sei();
  last_us = micros();
}

ISR(TIMER2_COMPA_vect) {
  PORTA &= ~0x3F;                 // end previous step pulses (>= 50 us wide)
  uint8_t out = 0;
  for (uint8_t j = 0; j < NUM_JOINTS; j++) {
    int32_t v = vel_q16[j];
    if (v == 0) continue;
    uint32_t mag = v > 0 ? (uint32_t)v : (uint32_t)(-v);
    acc_q16[j] += mag;
    if (acc_q16[j] >= 65536UL) {
      acc_q16[j] -= 65536UL;
      out |= (1 << j);
      pos_steps[j] += (v > 0) ? 1 : -1;
    }
  }
  PORTA |= out;
}

static void setDir(uint8_t j, float v) {
  bool fwd = (v >= 0) == (DIR_SIGN[j] > 0);
  digitalWrite(PIN_DIR[j], fwd ? HIGH : LOW);
}

void update() {
  uint32_t now = micros();
  float dt = (now - last_us) * 1e-6f;
  if (dt < 1.0f / CONTROL_HZ) return;
  last_us = now;
  if (dt > 0.05f) dt = 0.05f;
  for (uint8_t j = 0; j < NUM_JOINTS; j++) {
    int32_t p;
    ATOMIC_BLOCK(ATOMIC_RESTORESTATE) { p = pos_steps[j]; }
    float rem = (float)(target_steps[j] - p);
    float dir = rem > 0 ? 1.0f : (rem < 0 ? -1.0f : 0.0f);
    // fastest speed that still lets us stop at the target: v = sqrt(2 a d)
    float vstop = sqrtf(2.0f * axis_acc[j] * fabs(rem));
    float vdes = dir * min(axis_vmax[j], vstop);
    if (halted || fabs(rem) < 1.0f) vdes = 0;
    float dv = axis_acc[j] * dt;
    float v = vel_sps[j];
    if (vdes > v) v = min(v + dv, vdes); else v = max(v - dv, vdes);
    vel_sps[j] = v;
    // never exceed the ISR's 1-step-per-2-ticks limit
    float vmax_isr = STEP_ISR_HZ / 2.0f;
    if (v > vmax_isr) v = vmax_isr; else if (v < -vmax_isr) v = -vmax_isr;
    if (v != 0) setDir(j, v);
    int32_t q = (int32_t)(v / STEP_ISR_HZ * 65536.0f);
    ATOMIC_BLOCK(ATOMIC_RESTORESTATE) { vel_q16[j] = q; }
  }
}

static int32_t degToSteps(uint8_t j, float deg) {
  if (deg < LIMIT_MIN[j]) deg = LIMIT_MIN[j];
  if (deg > LIMIT_MAX[j]) deg = LIMIT_MAX[j];
  return (int32_t)lroundf(deg * spd[j]);
}

void setTarget(uint8_t j, float deg) { halted = false; target_steps[j] = degToSteps(j, deg); syncAxes(); }

void setTargets(const float deg[NUM_JOINTS]) {
  halted = false;
  for (uint8_t j = 0; j < NUM_JOINTS; j++) target_steps[j] = degToSteps(j, deg[j]);
  syncAxes();
}

void stopAll() {
  // new target = where we would stop from the current speed
  for (uint8_t j = 0; j < NUM_JOINTS; j++) {
    int32_t p;
    ATOMIC_BLOCK(ATOMIC_RESTORESTATE) { p = pos_steps[j]; }
    float v = vel_sps[j];
    float a = axis_acc[j] > 0 ? axis_acc[j] : 1.0f;
    float d = v * fabs(v) / (2.0f * a);
    target_steps[j] = p + (int32_t)d;
  }
}

void haltNow() {
  halted = true;
  for (uint8_t j = 0; j < NUM_JOINTS; j++) {
    vel_sps[j] = 0;
    ATOMIC_BLOCK(ATOMIC_RESTORESTATE) { vel_q16[j] = 0; target_steps[j] = pos_steps[j]; }
  }
}

void setVmax(float dps) { if (dps > 0) { vmax_dps = dps; syncAxes(); } }
void setAcc(float dps2) { if (dps2 > 0) { acc_dps2 = dps2; syncAxes(); } }

float positionDeg(uint8_t j) {
  int32_t p;
  ATOMIC_BLOCK(ATOMIC_RESTORESTATE) { p = pos_steps[j]; }
  return p / spd[j];
}
float targetDeg(uint8_t j) { return target_steps[j] / spd[j]; }

bool moving() {
  for (uint8_t j = 0; j < NUM_JOINTS; j++) {
    int32_t p;
    ATOMIC_BLOCK(ATOMIC_RESTORESTATE) { p = pos_steps[j]; }
    if (p != target_steps[j] || vel_sps[j] != 0) return true;
  }
  return false;
}

void setPositionDeg(uint8_t j, float deg) {
  int32_t s = (int32_t)lroundf(deg * spd[j]);
  ATOMIC_BLOCK(ATOMIC_RESTORESTATE) { pos_steps[j] = s; }
  target_steps[j] = s;
  vel_sps[j] = 0;
}

}  // namespace motion

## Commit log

2026-10-03 Add RoboArm plans: electronics schematic, BOM and project structure
    - Full-pin KiCad schematic (Pi 5, Arduino Mega, 6x TMC2209, AS5600 joint
    encoders, E-stop relay, gripper servo) with generator and netlist check
    - Amazon bill of materials
    - Architecture, roadmap and comparison docs
    - Placeholders for mechanical, firmware and software
    [bom.csv, custom_arm.kicad_sch]
2026-10-03 Add Mega firmware, Docker dev image and nothing-connected test tools
    - firmware/roboarm_mega: step generation, trapezoidal planning, AS5600
    encoders, TMC2209 UART setup/polling, text protocol, safety faults,
    RA_SIM build for running with nothing connected
    - software/docker: ROS 2 Jazzy dev image with Arduino CLI toolchain
    - software/tools: mock Mega, serial CLI and smoke test
2026-11-02 Add mechanical design, base and J1 model, simulator and phased BOM
    Set the arm layout: J1 base, J2 shoulder, J3 elbow, J4 wrist, J5 wrist
    twist, J6 swappable gripper, at Niryo Ned2 size.
    - Add joint sizing and the mechanical design document
    - Add the printable base and J1 model with fit checks
    - Add a MuJoCo simulator with browser controls
    - Rebuild the BOM by phase and by joint, marking parts already owned
    Firmware and schematic still describe six steppers; the changes they
    need are listed in docs/mechanical-design.md.
2026-11-02 Update schematic and firmware for five steppers, add gripper and calculations
    - Schematic rev D: five steppers, flyback diode, fan and tool plug
    - Firmware: five joints, real gear ratios, limits and motor currents
    - Add the two-jaw gripper model and printable files
    - Add engineering calculations for freedom, mass, torque, speed, power and tipping
    - Size the wrist for the real gripper length and update the BOM
2026-11-02 Add J2 shoulder model and printable files
    - Add the J2 housing, arm root and 100T pulley with fit checks through full travel
    - Notch the J1 turntable so the J2 pulley clears it
    - Set the J2 belt to 280 mm and update the BOM and design notes
2026-11-02 Slim the base and add J3 upper arm with wire tunnel
    - Taper the base shell and shorten the J1 belt to 360 mm
    - Add the slim upper arm with lid, belt bay and wire clips
    - Add the elbow stem and 80T pulley, with a 380 mm belt
    - Remove the extrusion spine and update the BOM and calculations
    - Add a browser 3D model of the arm
2026-11-02 Add mounting plate and per-joint colours
    - Add a clampable plate that the base bolts down to
    - Give each joint one colour in the 3D model and design notes
    - Add the plate hardware to the BOM
2026-11-02 Fix turntable height after mounting plate change
    The mounting plate thickness had overwritten the turntable plate constant.
    Rename it and regenerate the printable files.
2026-11-02 Add J4 forearm and wrist hinge
    - Add the slim forearm with lid, wire clips and belt bay
    - Add the compound pulley, wrist pulley and wrist link
    - Limit J3 to +50 degrees, where the forearm meets the upper arm
    - Show the forearm and J4 travel in the 3D model
    - Remove the metal rods and update the BOM and calculations
2026-11-02 Enclose the J4 motor pulley in the forearm hump
    The motor pulley sat above the forearm tube, outside the skin.
    Extend the hump over the first belt stage and regenerate the printable files.
2026-11-02 Add J5 and finish the arm, with print-ready files
    - Add the wrist housing, spindle and tool flange, and fit the gripper
    - Switch J5 to the short 11HS12 motor with a 4:1 belt
    - Raise J4 to 18.75:1 for the longer wrist and limit it to -50 degrees
    - Add parts laid flat for slicing, and print settings
    - Update the schematic, firmware, simulator, BOM and calculations
2026-11-02 Add carrier board layout and wiring guide
    - Add a hole-by-hole 7 x 9 cm perfboard plan, checked against the netlist
    - Add a wire list, Mega plug map, off-board wiring and bring-up steps
    - Schematic rev E: correct driver pin names and tie encoder GPO to 5 V
    - Move base standoffs and one deck post to fit the board
2026-11-02 Update the BOM and electronics README for the carrier board
